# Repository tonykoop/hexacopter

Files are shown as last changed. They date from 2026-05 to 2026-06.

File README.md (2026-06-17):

# Hexacopter — Systems Integration for a Deliberately Grounded Aerial Platform

> *I was one of the first hobby DJI Phantom owners. I got beautiful aerial skyline photos — 10 of which were later juried into the permanent collection of the University of Minnesota Ambulatory Care Center through Art Force. I lost the Phantom to a fly-away during a demo at Bracketron. The community rebuilt me through a Kickstarter funded at 168% of goal by 94 backers. The replacement is a six-rotor DSLR-lift platform with a 3D-printed gimbal that I intentionally kept grounded until the flight-control stack could be validated. This repository is the engineering record of that build.*

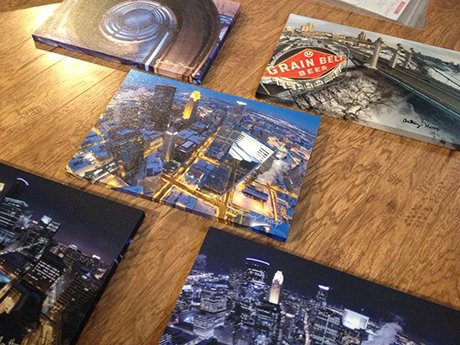
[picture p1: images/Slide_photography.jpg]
Phantom-era Minneapolis aerial skyline photographs printed as canvas wraps, laid out on a wood table


*Phantom-era Minneapolis aerials, printed as canvas wraps — the body of work the Kickstarter backers funded a more capable platform to extend.*

## What this is

Engineering documentation for a hexacopter aerial-photography platform that I designed, sourced, partially assembled, and then deliberately paused before flight testing. The next step was firmware-level speed-controller and flight-controller setup, and I was not willing to risk a multi-thousand-dollar crowdfunded airframe on a maiden flight that had not cleared a convincing validation path.

The build is currently at my parents' house, intact, ready to be picked up again. This repository captures the engineering work that *did* happen: the BOM, the design choices, the sketchbook entries, the engineering-notebook pages, the 3D-printed gimbal, the CAD, independent of the airframe ever flying.

## The story

### Phantom era — early adopter, beautiful aerials

I was one of the first hobby owners of the **DJI Phantom** when it launched in 2013. I got a string of beautiful aerial skyline photos that, for a brief moment before consumer drones became ubiquitous, felt like access to a perspective hardly anyone else had.

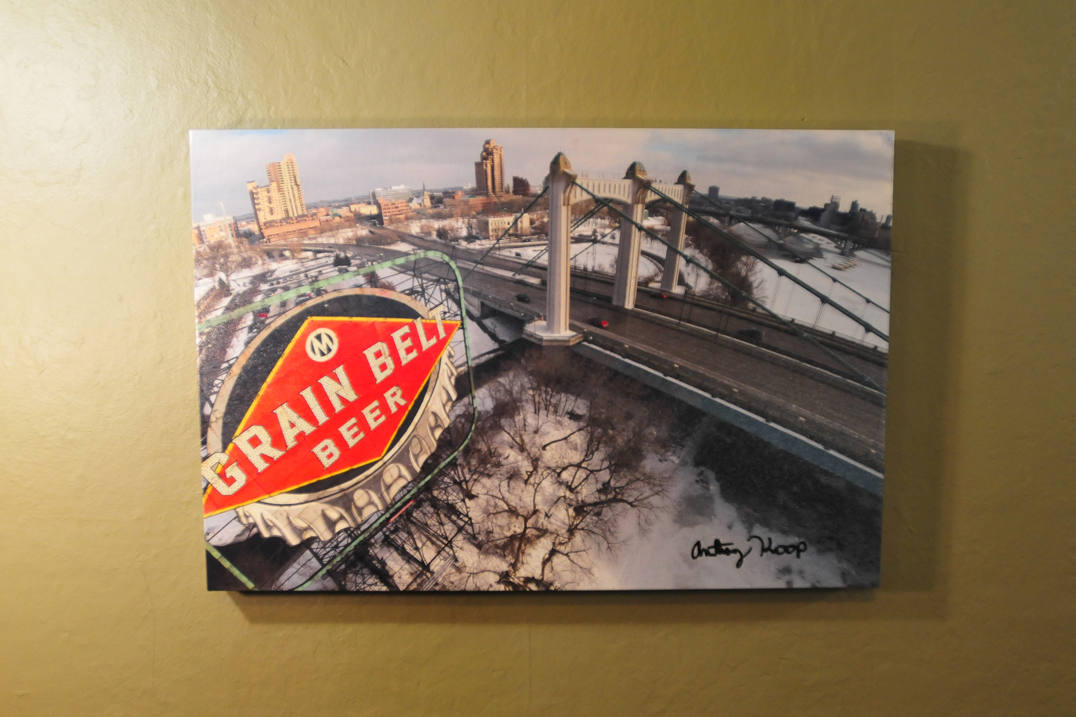
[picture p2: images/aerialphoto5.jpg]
Aerial photograph of the Grain Belt Beer sign and the Hennepin Avenue Bridge over the Mississippi River, printed as a signed canvas wrap


*A Phantom-era aerial — the Grain Belt Beer sign and the Hennepin Avenue Bridge over the Mississippi — printed as a signed canvas wrap.*

### Aerial work juried into a healthcare-facility installation

In September 2015, **Art Force** — the curatorial program that places original art into University of Minnesota healthcare facilities — juried **21 of my photographs into the permanent collection at the U of M Ambulatory Care Center**, including 10 aerial images. The selection was a paid licensing arrangement ($30 per use × 21 images), and the photographs have been printed and installed in the clinic since.

The aerial pieces in that collection are part of the same body of work the Kickstarter backers funded a more capable drone to extend.

### The fly-away

During a demonstration to coworkers at **Bracketron**, the Phantom executed a fly-away and was never seen again. Fly-aways were a known failure mode of early hobby drones; mine was almost certainly a compass-calibration or GPS-handoff event, but the diagnosis did not change the outcome. The drone and the GoPro mounted to it were gone. Coworkers, my brother, and I spent something like 20–30 collective hours ground-searching the area and never recovered it.

### Crowdfunded rebuild — the hexacopter

In March 2014 I launched a **Kickstarter** to crowdfund a more capable replacement aerial-photography platform. The campaign ran March 3 – April 1, 2014 and raised **$5,065 from 94 backers** — **168% of the $3,000 goal** — over 29 days. Backers were a mix of friends, coworkers, and strangers who had seen the Phantom-era aerial photos.

With the funds I:

- sourced a pre-built hexacopter frame kit specced for **DSLR camera lift capacity**
- selected and procured the electronics: flight controller, ESCs, motors, props, telemetry radio, FPV transmitter, receiver, and batteries
- designed and **3D-printed a custom gimbal** for the DSLR payload
- mechanically assembled the airframe, gimbal, and electronics
- wired the power distribution, signal lines, and telemetry

Four carbon-fiber motor arms with brushless motors and ESCs, laid out beside a digital caliper and steel rule

*Carbon-fiber motor arms with their brushless motors and ESCs, checked against a digital caliper and steel rule — component verification from the build.*

**Rewards delivered:** signed aerial prints (8″×10″, 11″×14″, 12″×18″), canvas wraps, and the bill-of-materials / build-log document.

**Reward still outstanding:** The top-tier backer reward — an aerial photo/video shoot within 250 miles of Minneapolis — was never delivered, because the platform never had its maiden flight. The build is paused, not closed.

### The decision to keep it grounded

The next step in 2014 was tuning: program the **speed controllers** (ESCs), configure the **flight controller** firmware, set up failsafes, and then fly increasingly careful test hops. I trusted the mechanical and electrical work. I did not yet trust the validation path strongly enough to put a crowdfunded aircraft in the air.

So I kept it grounded. The hexacopter went into storage at my parents' house and has been waiting since.

The engineering judgment I have made peace with is simple: **keeping it grounded was the right call at the time.** Hobby drone crashes from misconfigured firmware are common, and this build deserved a stronger validation chain than I had in hand. The good news is that the project is resumable rather than lost; the documentation ecosystem around platforms like ArduPilot, PX4, simulators, and safer bench-testing workflows is much better now than it was when I first built it.

## Why an unfinished build still belongs in the portfolio

The value here is not "I launched it." The value is in two things together:

**1. The documented systems work that did happen.**
- **Bill of materials** — a complete, sourced, costed component list for a DSLR-lifting hexacopter
- **Mechanical design** — frame selection, motor and prop choices, gimbal CAD, payload geometry
- **3D-printed gimbal** — early mechanism design work
- **Electronics architecture** — power distribution, ESC and flight-controller integration, telemetry radio, FPV link
- **Sketchbook and engineering-notebook entries** — design decisions and tradeoff thinking from the time, including first-principles geometric analysis of motor-to-prop clearance across quad/hex/octocopter configurations (June 2013)
- **Cross-domain integration** — mechanical, electrical, embedded firmware, data comms, and payload optics

**2. The decision to stop before flying.**
A maiden flight on an unvalidated stack carrying a crowdfunded airframe was a bad risk. The same judgment that says "do not fly this yet" is the judgment a UAV company wants in someone touching their hardware. Hobby drone crashes are common; this one didn't crash because I chose not to put it in the air.

A senior R&D engineer reading this should see: *here is someone who took on a multi-disciplinary integration project, carried the mechanical and electrical work to assembly, recognized when the validation gate for safe execution had not been met, and kept the platform grounded rather than bluffing past that limit.* That is the signal this repo is meant to carry.

## Engineering content (forthcoming)

Material exists in personal archives and at my parents' house; it will be added as recovered. README, license, and an initial set of photos are in; the engineering documents are being recovered from archives.

| Section | Status |
|---|---|
| Repo description, license | ✓ done |
| Story arc + framing | ✓ this README |
| Phantom-era aerial photos | ✓ done — hero + in-page aerial added |
| Selected Art Force / U of M Ambulatory Care Center pieces | forthcoming — selection of the 10 aerial images installed |
| Bill of materials | forthcoming — exists in engineering notebook |
| Mechanical design — frame + motor sizing | forthcoming |
| 3D-printed gimbal CAD + photos | forthcoming |
| Electronics architecture diagram | forthcoming |
| Sketchbook + engineering-notebook scans | forthcoming (parents' house archives) — June 2013 quad/hex/octocopter clearance derivations are top priority |
| Build photos | ✓ done — component-check photo added; more forthcoming |
| Firmware-tuning plan (for resumption) | forthcoming — ArduPilot / PX4 evaluation, bench-testing sequence, tethered-hover gate, maiden-flight gate |
| Outstanding-backer shoot list (private) | forthcoming — internal tracking, not for public posting |

## Cross-references

- **Art Force / U of M Ambulatory Care Center placement** — Aerial photographs selected for the permanent clinic installation are the body of work this hexacopter was built to extend. Documented in personal archives; selection licensed September 2015.
- **[wrfcoin](https://www.wrfcoin.com)** — a finished hexacopter would make an excellent **mobile sensor platform** for wrfcoin: the current sensor work is fixed-location ground-station based, but a UAV-mounted instrument package could capture vertical atmospheric profiles, micro-climate variation, and remote-area weather data the ground stations cannot reach.
- **General engineering portfolio** — this is the multi-disciplinary integration project in the personal-craft cluster, alongside [`woodworking`](https://github.com/tonykoop/woodworking) and [`chessboard-table`](https://github.com/tonykoop/chessboard-table). Where those repos document hand-craft, this one documents systems-engineering thinking applied to a hobby project.

## Repository structure

```text
hexacopter/
├── README.md                  ← you are here
├── LICENSE                    ← CC-BY 4.0
├── images/                    ← Phantom skyline photos, build photos, gimbal renders
└── (forthcoming)
    ├── art-force/             ← selection of the 10 aerial images installed at U of M
    ├── CAD/                   ← gimbal + payload-mount geometry
    ├── BOM/                   ← bill of materials, sourcing notes
    ├── electronics/           ← architecture diagram, ESC + FC documentation
    ├── notebook/              ← scanned sketchbook + engineering notebook entries
    └── firmware-plan/         ← tuning + maiden-flight plan (for resumption)
```

## License

Released under [CC-BY 4.0](LICENSE) — original written content, CAD, BOM, photographs, and engineering analysis in this repository are mine, free to reuse and adapt with credit. **Component selections and sourcing decisions documented here are personal-build choices for a hobby project; reproduce at your own risk.** The aerial photographs licensed to Art Force for the U of M Ambulatory Care Center installation are covered separately by that licensing arrangement and are not part of this CC-BY release.

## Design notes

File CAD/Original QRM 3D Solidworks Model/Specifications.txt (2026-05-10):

Dimensions*:		165 x 165 x 52 mm
Weight**:		200 gr
Battery:		2S 850mAh
Motor size:		18  x11 - 2000kv
Prop size:		5”
Control board size:	50 x 50 mm
Control board mounting:	4x M3 (44 x 44 mm)
Flyingtime:		+- 6min

* without propellers
** excluding battery

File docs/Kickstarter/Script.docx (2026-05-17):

OVERVIEW
1. Intro
2. Multirotor Frame

a. Tools needed to work with frames
b. Variety of frames
i. tri, quad, hex, octo,
ii. Y6, X8,
c. Common Dimensions
3. Flight Controller

a. Tools needed
b. What they do
c. common components & features to look for
d.

4. Transmitters

a. how they work with receivers
b. actual size image

5. Receivers
6. Camera

a. Commonly used for aerial photograpy
b. Interfaces with gimbal, telemetry
c. actual size image of gopro

7. Gimbal

a. What they do
b. How they work with receiver and flight controller

8. Motor

a. KV explanation
b. image of actual size motor
c.

9. ESC

10. Battery
11. Propellers
12. Other Accessories

RESEARCH

- DATABASE CREATION
- PART ELIMINATION/SELECTION
- PURCHASING

ASSEMBLY
1. Frame
2.
BATTERY CARE
FLIGHT CONTROLLER PROGRAMMING
TRANSMITTER PROGRAMMING
- RECEIVER BINDING

I have just concluded the data collection process (online shopping) for creating a Bill of Materials Database. It is the Excel spreadsheet named “BOM Database.xls”. I hope this document will be an invaluable tool for customizing your own build. I also just finished the first round of part elimination which I will explain below.

There are 8 main components to every basic DIY multirotor. They are highlighted in blue below. Those highlighted in yellow are the accessories for my customized build.

ITEM NO. | CATEGORY | COMPONENT | OPTIONS
1 | Hardware | Multirotor Frame | 21
2 | Electronics | Flight Contoller | 7
3 | Electronics | Transmitter | 13
4 | Electronics | Receiver | 8
5 | Accessories | Camera | 7
6 | Accessories | Gimbal | 7
7 | Electronics | Motor | 37
8 | Electronics | ESC | 23
9 | Electronics | Battery | 17
10 | Hardware | Propellers | 28
11 | Accessories | GPS Tracker | 1
| | # OF TOTAL POSSIBLE COMBINATIONS: | 303,447,292,512

Choose Specifications for your build:
When undertaking the task of building a multirotor, it’s important to first determine what you want to do with your multirotor. Applications and industries include but are not limited to aerial photography and videography, agricultural inspections, infra-red night vision, search and rescue, wildfire control, natural disaster surveillance, relief aid distribution, local package delivery, and real estate sales etc.

I have decided to build a hexacopter or octocopter capable of GPS stabilized flight, camera stabilization, first person view (FPV) transmission, and it must include a GPS tracker with an independent power source. This craft should have landing gear that easily allow for the addition of a camera gimbal. The central portion of the frame should be large enough to house the flight controller, GPS tracker, LED, batteries, and receiver.

Excel Spreadsheet: BOM Database
There are 13 tabs within the BOM Database. One tab each for the eleven components listed above, one called “BOM Summary” and another called “Scorecard”. If you have the document open within Excel, you’ll notice all the tabs near the bottom of the screen. Select the second tab labeled “1. Multirotor Frames”. There you’ll find 21 frame options with relevant data such as mass, price, distance between motor centers, and max prop size etc. The far right column in the table above indicates how many part options are available for that specific component. You are encouraged to add other parts from your own research to the database. This will help you find the best possible combination of parts. And there are literally billions of options. If one were to attempt a multirotor build by throwing a dart in the dark at each of the component lists, there would literally be 303 billion possible combinations. We’ll use some neat tricks in Excel to narrow down the number of possible options. Note: Please verify and double check that any data you use from the BOM Database is correct before purchasing and assembling your own multirotor.

What order to choose your components:
I suggest choosing your components in numerical order as shown in the table above. The first list of parts to narrow down are the multirotor frames followed by the flight controller, transmitter, and receiver. In this case, two accessories come next; the camera and the gimbal. I have put these before the motors, ESCs, and batteries because they contribute a significant amount of weight to the build. The final components to consider are any other accessories, in my case I’m adding an independent GPS tracker.

Round 1 of Elimination:
After having collected data on all the parts I’m considering for my build, I then begin to narrow down the options to those that suit my budget and needs. How you narrow down the parts for your build also depends on your budget and needs. During the first round of elimination on the frames I removed the most expensive frames and the smallest frames. This leaves me with 9 remaining frame options

1. Multirotor Frames

A similar process was conducted for the flight controllers, transmitters, receivers, cameras, gimbals, and motors. Two of the seven flight controllers were removed due to budget constraints. Choosing a transmitter to fly the craft was easy because I already own one. The receiver was also easy to choose because I plan to use the receiver recommended for my transmitter. I already own the camera I plan to use and all gimbals incompatible with my GoPro camera have been removed from consideration. This first round of elimination reduced the number of possible combinations by 99.98%. But remember 303 billion is a huge number, we still have 49.3 million possible combinations. Hopefully the second round of elimination will significantly reduce this number again, especially considering we haven’t eliminated any ESCs, batteries, or propellers yet.

BOM Summary – Sub Table 3

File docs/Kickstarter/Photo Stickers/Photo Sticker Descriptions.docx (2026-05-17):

Option 1 - Done

Ramp Sprial #1

This photo was taken with a GoPro Hero 3+ Black Edition camera on a DJI Phantom Quadcopter flown by Tony Koop on January 17th, 2014 at 6:17pm. The objective of this flight was to capture the Minneapolis skyline. While returning for landing, I noticed the unusual perspective of this parking ramp and knew I had to shoot it. This was shot during the same flight as Downtown Minneapolis #2.

Option 2 - Done

Grain Belt Beer

This photo was taken with a GoPro Hero 3+ Black Edition camera on a DJI Phantom Quadcopter flown by Tony Koop on January 11th, 2014 at 2:11pm. This sign was originally erected in 1941 for $5000. The circumscribed letter M is a tribute to the brewery’s former name, Minneapolis Brewing Company. Grain Belt is now owned by August Schell Brewing Company which purchased the rights in 2002.

Option 3 - Done

Downtown Minneapolis #1

This photo was taken with a GoPro Hero 3+ Black Edition camera on a DJI Phantom Quadcopter flown by Tony Koop on January 11th, 2014 at 7:24pm. My initial objective for this flight was to photograph the Orpheum Theatre. It turned into my first attempt at photographing the Minneapolis skyline when I couldn’t quite get the perspective I wanted of the Orpheum.

Option 4

Minneapolis from Loring Park

This photo was taken with a GoPro Hero 3+ Black Edition camera on a DJI Phantom Quadcopter flown by Tony Koop on January 11th, 2014 at 2:41pm.

Option 5

Downtown Saint Paul

This photo was taken with a GoPro Hero 3+ Black Edition camera on a DJI Phantom Quadcopter flown by Tony Koop on January 18th, 2014 at 4:08pm.

Option 6 – Done

Downtown Minneapolis #2

This photo was taken with a GoPro Hero 3+ Black Edition camera on a DJI Phantom Quadcopter flown by Tony Koop on January 17th, 2014 at 6:14pm. It was the night before the Metrodome fell to make way for the new stadium. Damn it was cold. The atmosphere was crystal clear and frigid at 6°F as shown on the TCF Tower just to the right of the Foshay. Three minutes later I shot Ramp Spiral #1.

Option 7

Downtown Minneapolis #3

This photo was taken with a GoPro Hero 3+ Black Edition camera on a DJI Phantom Quadcopter flown by Tony Koop on January 18th, 2014 at 5:29pm.

Option 8

Target HQ

This photo was taken with a GoPro Hero 3+ Black Edition camera on a DJI Phantom Quadcopter flown by Tony Koop on January 29th, 2014 at 6:05pm. The display at the top of this building was upgraded from 3M light pipes to LEDs in 2011, just ten years after the building properly known as Target Plaza South was completed.

Option 9 - Done

Loring Park

This photo was taken with a GoPro Hero 3+ Black Edition camera on a DJI Phantom Quadcopter flown by Tony Koop on January 11th, 2014 at 2:46pm. If you look closely - which I’m sure you will – you might notice some interesting footprint patterns in the snow. Now known as Loring Park and Loring Lake, this park that butts up next to downtown was originally named Central Park and Johnson Lake.

Option 10

Ramp Spiral #2

This photo was taken with a GoPro Hero 3+ Black Edition camera on a DJI Phantom Quadcopter flown by Tony Koop on January 18th, 2014 at 4:14pm. Having been inspired by the first ramp I shot in Minnepolis, I attempted to shoot this ramp at the Science Museum of Minnesota in downtown Saint Paul.

Option 11 - Done

The Secret Option

This photo was taken with a GoPro Hero 3+ Black Edition camera on a DJI Phantom Quadcopter flown by Tony Koop on January 29th, 2014 at 5:39pm. This is a one of a kind. No other Kickstarter backers received this photo. The Basilica of Saint Mary was established by Pope Pius XI and was the first basilica in the US.

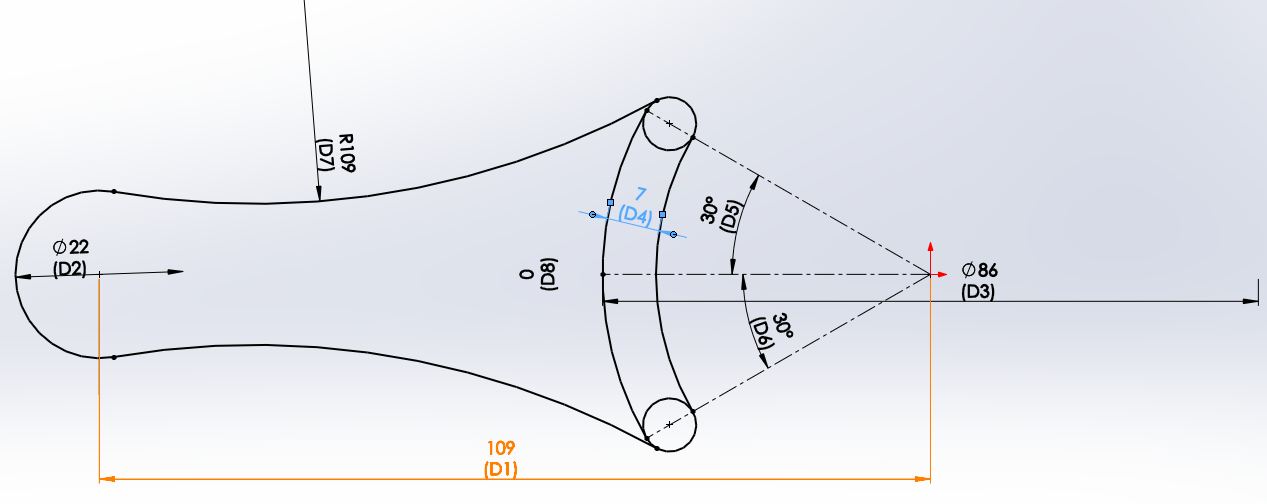
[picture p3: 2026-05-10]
CAD/Quadcopter/Bottom Arm Design Table Parameters.JPG

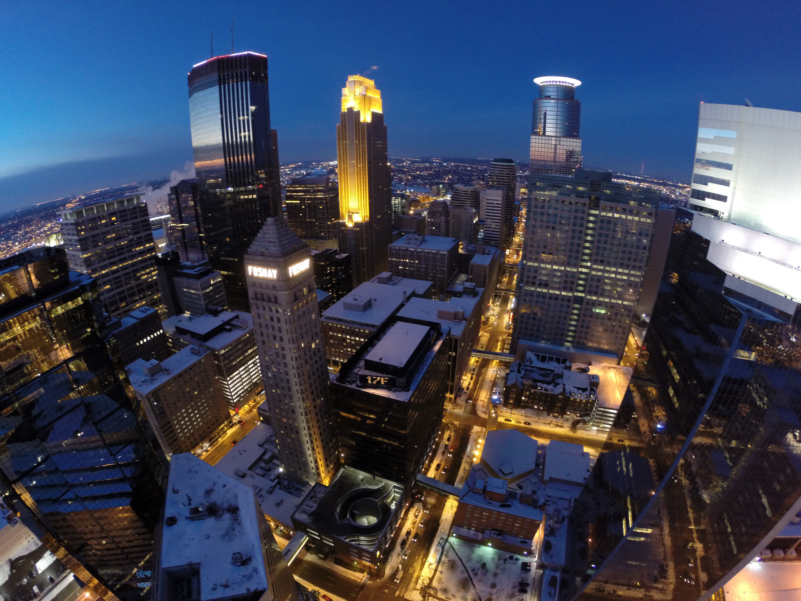
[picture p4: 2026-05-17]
docs/Kickstarter/WHCC/B Side/G0052918.JPG

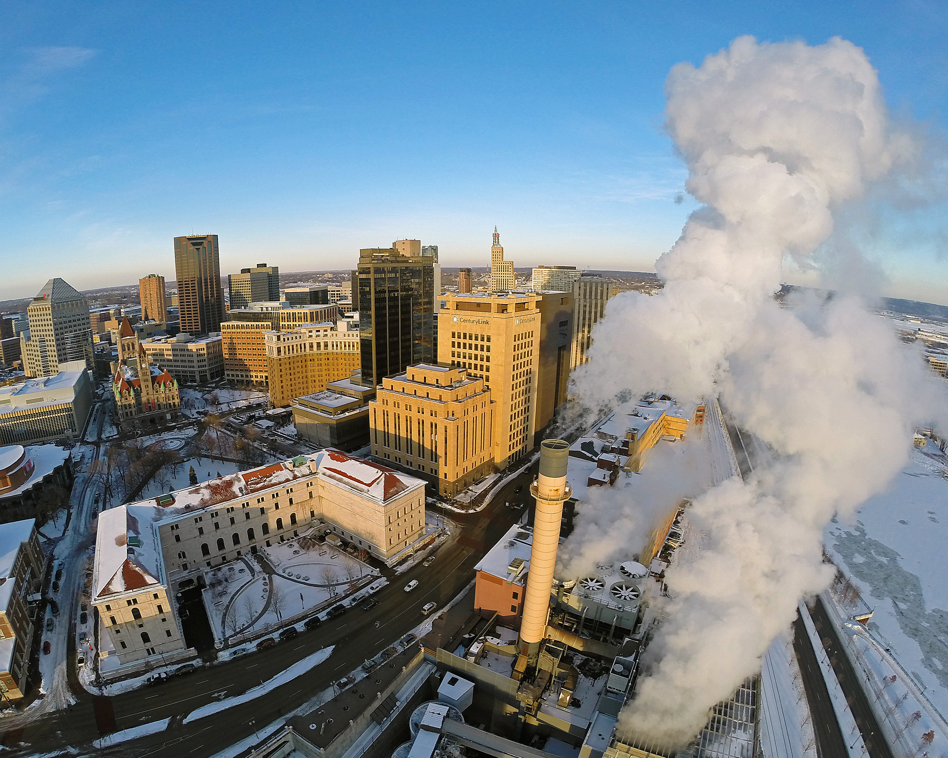
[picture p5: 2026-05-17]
docs/Kickstarter/Replacement photos/G0032023e810.jpg

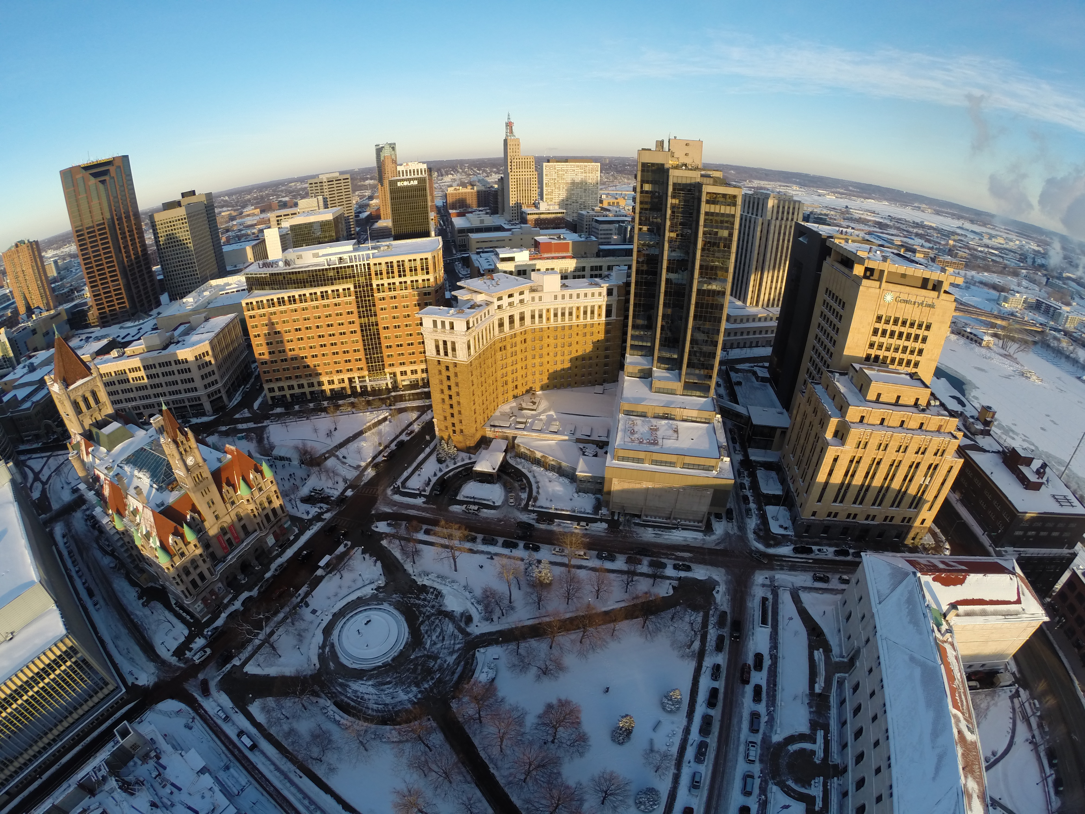
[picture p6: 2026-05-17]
docs/Kickstarter/WHCC/B Side/G0032110.JPG

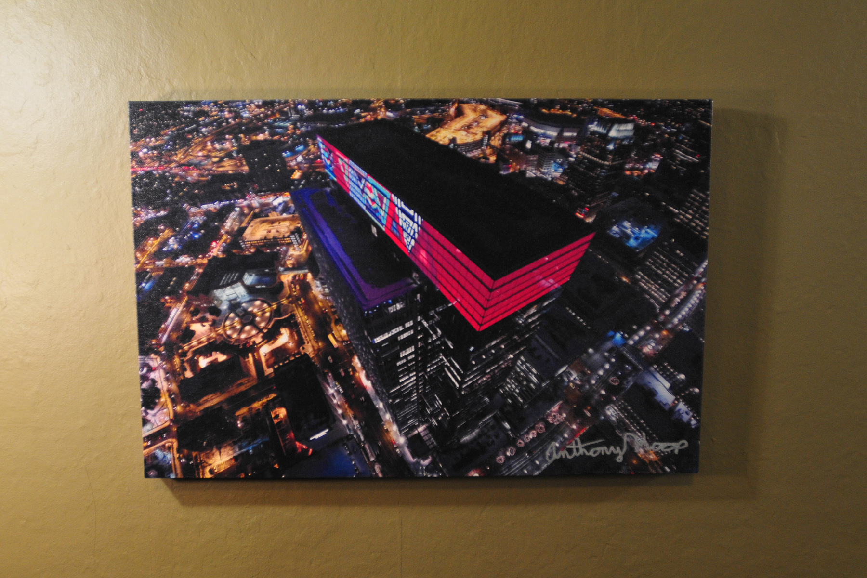
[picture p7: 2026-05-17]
images/aerialphoto6.jpg

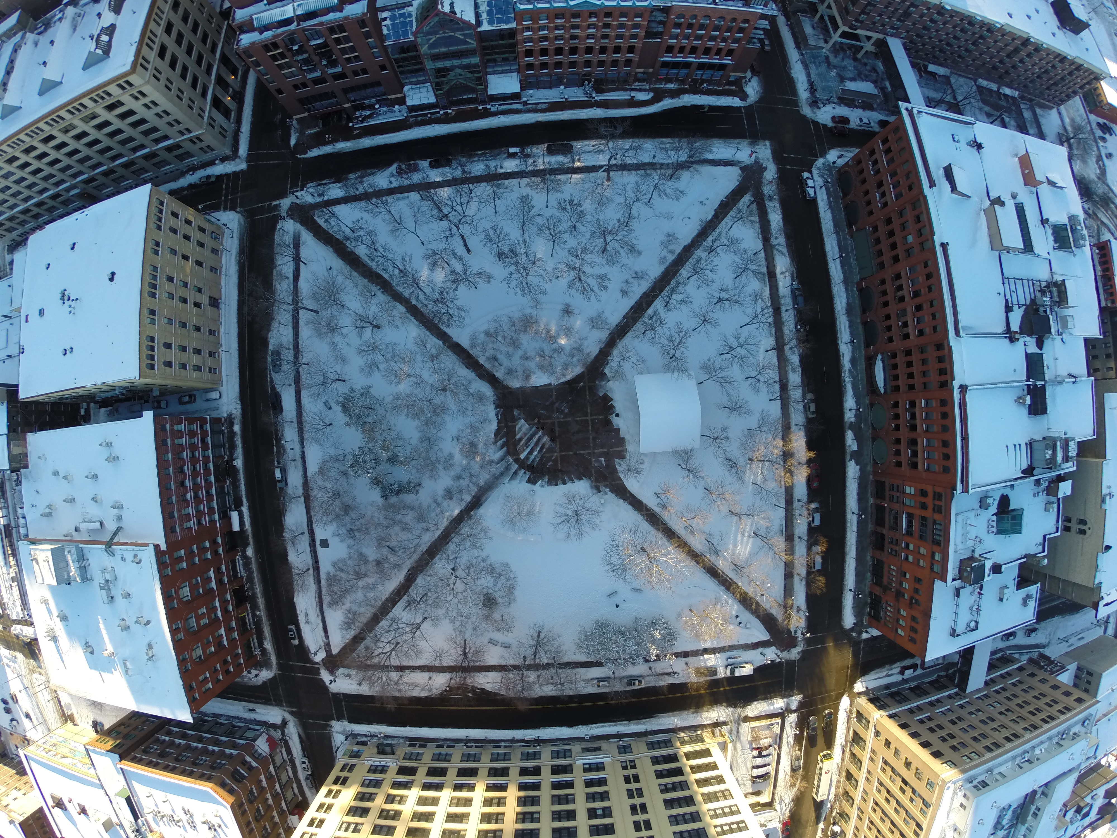
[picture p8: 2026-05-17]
docs/Kickstarter/WHCC/B Side/G0021763.JPG

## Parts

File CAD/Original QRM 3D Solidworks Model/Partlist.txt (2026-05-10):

Motor: 		18-11 2000kv Micro Brushless Outrunner (10g)
ESC: 		H-KING 10A Fixed Wing Brushless Speed Controller
Props: 		5x3 Propellers (Standard and Counter Rotating) (6pc)
Prop adaptors: 	Prop adapter w/ Alu Cone M5x2mm shaft (Grub Screw Type)
Battery: 	Turnigy nano-tech 850mah 2S 25~40C Lipo Pack
Control board: 	HobbyKing Quadcopter Control Board V2.1 (Atmega168PA)

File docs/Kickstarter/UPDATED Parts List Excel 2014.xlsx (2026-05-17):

Parts List
ITEM | PART DESCRIPITION | REF. DES. | PART NUMBER | QUANTITY | UNIT COST | EXTENDED COST | WEB ADDRESS
1 | HK Pilot Mega V2.5 | APM 2.5 | 9387000016 | 1 | 75.79 | 75.79 | http://hobbyking.com/hobbyking/store/__37328__HKPilot_Mega_V2_5_Flight_Controller_USB_GYRO_ACC_MAG_BARO.html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
2 | NEO-6M GPS Module | GPS | 387000004 | 1 | 22.49 | 22.49 | http://hobbyking.com/hobbyking/store/__54795__NEO_6M_GPS_Module_US_Warehouse_.html?strSearch=neo%206m
3 | NTM Prop Drive 28-36 1000kV Brushless Motors | MOTOR | 281052552799 | 8 | 16.12 | 128.96 | http://hobbyking.com/hobbyking/store/__42709__NTM_Prop_Drive_28_36_1000KV_400W_Brushless_Motor_US_Warehouse_.html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
4 | NTM Prop Drive 28 Brushless Motor Adapter | ADAPTER | NTM28-ACC | 8 | 1.89 | 15.12 | http://hobbyking.com/hobbyking/store/__16719__NTM_Prop_Drive_28_Series_Accessory_Pack.html
5 | AFRO 30A Speed Control | ESC | 9192000124-0 | 8 | 13.97 | 111.76 | http://hobbyking.com/hobbyking/store/__52338__Afro_ESC_30Amp_Multi_rotor_Motor_Speed_Controller_SimonK_Firmware_US_Warehouse_.html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
6 | AFRO ESC Programmer | ESC PROG. | 9171000243 | 1 | 7.35 | 7.35 | http://hobbyking.com/hobbyking/store/__48057__Afro_ESC_USB_Programming_Tool_USA_Warehouse_.html
7 | Turnigy 4s 5000mAh LiPo battery | BATTERY | T50004S-20HC | 4 | 25.47 | 101.88 | http://hobbyking.com/hobbyking/store/__18631__Turnigy_5000mAh_4S1P_14_8v_20C_hardcase_pack_USA_Warehouse_.html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
8 | 11x4.7 Carbon Fiber Propeller | PROP | 445000049-0 | 6 | 8.19 | 49.14 | http://hobbyking.com/hobbyking/store/__25689__Carbon_Fiber_Propellers_11X4_7_LH_and_RH_Rotation_Pair.html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
9 | Boscam 2000mW 5.8 GHz Video Transmitter | VID. TX | 263000022-0 | 1 | 123.48 | 123.48 | http://hobbyking.com/hobbyking/store/__46362__Boscam_Thunderbolt_2000mW_5_8GHz_FPV_Transmitter.html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
10 | Boscam 5.8GHz receiver | VID. RX | RC305Receiver | 1 | 24.99 | 24.99 | http://hobbyking.com/hobbyking/store/__15415__Boscam_RC305_5_8Ghz_8_Channel_AV_Receiver.html?strSearch=rc305
11 | 7in TFT Analog Screen | SCREEN | BW7MY | 1 | 31.28 | 31.28 | http://www.amazon.com/gp/product/B007SLDF7O/ref=oh_details_o06_s00_i00?ie=UTF8&psc=1
12 | 433 MHz Telemetry Combo | TELEMETRY | 9387000030-0 | 1 | 32.04 | 32.04 | http://hobbyking.com/hobbyking/store/__42847__FPV_433Mhz_Radio_Telemetry_Kit_100mW_V1_1.html
13 | Turnigy 9X 2.4GHz Transmitter & Receiver | TRANSMITTER | TX-9X-M2 | 1 |  | 69.97 | http://hobbyking.com/hobbyking/store/__19673__Turnigy_9X_9Ch_Transmitter_w_Module_8ch_Receiver_Mode_2_v2_Firmware_USA_Warehouse_.html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
14 | Sony CCD 700TVL Camera | CAM | 350000001 | 1 |  | 34.74 | http://hobbyking.com/hobbyking/store/__13197__1_3_inch_Sony_CCD_Video_Camera_700TV_Lines_F1_2_PAL_.html
15 | 2.8mm FPV Wide Angle Lens | N/A | FPV_CCDN | 1 | 16.99 | 16.99 | http://hobbyking.com/hobbyking/store/__13434__1_3_inch_SONY_CCD_Video_Camera_NTSC_.html
16 | MinimOSD | OSD | 387000015 | 1 | 19.9 | 19.9 | http://hobbyking.com/hobbyking/store/__54797__Minim_OSD_v1_1_US_Warehouse_.html
17 | FTDI Breakout Board | FTDI | 9716 | 1 | 14.95 | 14.95 | https://www.sparkfun.com/products/9716
18 | Circular Polarized 5.8 GHz antenna set SHORT | ANT. | 435000044-0 | 1 | 11.34 | 11.34 | http://hobbyking.com/hobbyking/store/__43703__5_8GHz_Circular_Polarized_Antenna_RP_SMA_Set_Short_.html
19 | Turnigy 3s 2200 Transmitter Pack | TRANS BATT. | 9171000183 | 1 | 13.17 | 13.17 | http://hobbyking.com/hobbyking/store/__45020__Turnigy_9XR_Safety_Protected_11_1v_3s_2200mAh_1_5C_Transmitter_Pack_USA_warehouse_.html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
20 | .75in Aluminum Square Tubing 6ft | LANDING | 215691 | 1 | 22.88 | 22.88 | http://www.lowes.com/pd_215691-37672-11388_0__?productId=3053575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
21 | .5in Aluminum Square Tubing 4ft | ARMS | T312063 | 1 | 4.98 | 4.98 | https://www.metalsdepot.com/products/alum2.phtml?page=tube&LimAcc=%20&aident=
22 | McMasterCarr Bolts | N/A | N/A | 1 | 20 | 20 | http://www.mcmaster.com/
23 | McMasterCarr Rubber | N/A | 8981K14 (http://www.mcmaster.com/OrdHist/OrdHist.aspx?dtrngpref=ONE_YR) | 1 | 7.83 | 7.83 | http://www.mcmaster.com/#catalog/120/3546/=rrqa0g
24 | Zip Ties | N/A | N/A | 3 | 5 | 15 | Walmart.com
25 | Low Voltage Alarm | ALARM | Voltage-Alarm | 2 | 3.92 | 7.84 | https://www.hobbyking.com/hobbyking/store/__34120__Hobbyking_2_8S_Cell_Checker_with_Low_Voltage_Alarm_US_Warehouse_.html
26 | XT60 Battery Connector | N/A | 015000103-0 | 2 | 4.69 | 9.38 | https://www.hobbyking.com/hobbyking/store/__52412__Black_XT60_Male_and_Female_5_Pairs_Bag_US_Warehouse_.html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
27 | 12 Gauge Wire 6ft. | N/A | R12A1062-06 and B12A1062-06 | 2 | 2.38 | 9.52 | https://www.hobbyking.com/hobbyking/store/__42750__Turnigy_Pure_Silicone_Wire_12AWG_1mtr_RED_USA_warehouse_.html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 | https://www.hobbyking.com/hobbyking/store/__41169__Turnigy_Pure_Silicone_Wire_12AWG_1mtr_BLACK_USA_warehouse_.html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
28 | Various Wire Shielding | N/A | ES-02-6mm | 6 | 0.49 | 2.94 | https://www.hobbyking.com/hobbyking/store/__9552__Wire_Mesh_Guard_Black_6mm_1mtr_.html
29 | HXT 4.0 | N/A | AM1009x10 | 2 | 4.46 | 8.92 | https://www.hobbyking.com/hobbyking/store/__30921__HXT_4mm_Gold_Connector_w_Protector_10pcs_set_US_Warehouse_.html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
30 | HD DVR | DVR | 428000001 | 1 | 52.22 | 52.22 | https://www.hobbyking.com/hobbyking/store/__25321__SD_DVR_High_Resolution_Digital_Video_Recorder_for_FPV.html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
TOTAL: |  |  |  |  |  | 1066.85
OPTIONAL, BUT RECOMMENDED:
1 | HK Pilot Mega Bundle |  | 387000043-0 | 1 | 169.99 | 169.99 | http://hobbyking.com/hobbyking/store/__52391__HKPilot_Mega_2_5_2_Master_Set_With_OSD_LEA_6H_GPS_Power_module_Telemetry_Radio_915Mhz_XT_60_.html
2

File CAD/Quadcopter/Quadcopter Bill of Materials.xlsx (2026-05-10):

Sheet: Scorecard
Elective BOM Option | Motor Model | Hover Flight Time (minutes) | Hover Score | Weight (grams) | Weight Score | Additional Payload (grams) | Additional Payload Score | Throttle at Hover (%) | Throttle At Hover Score | Total Price($US) | Price | Total Score (higher is better) | Weighted Total Score Option 1 | Weighted Total Score Option 2 | ecalc Link
7 | 4822-490 | 14.8 | 7 | 2011 | 3 | 454 | 1 | 65.00 | 1.00 | $441.21 | 3 | 15 | 25 | 34.25 | Link (http://www.ecalc.ch/xcoptercalc.htm?ecalc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)
6 | 4822-390 | 19.2 | 10 | 2239 | 1 | 1191 | 5 | 50.00 | 4.00 | $472.83 | 1 | 21 | 35.5 | 46.25 | Link (http://www.ecalc.ch/xcoptercalc.htm?ecalc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)
10 | 4225-390 | 19.9 | 11 | 2191 | 2 | 1106 | 3 | 51.00 | 3.00 | $460.83 | 2 | 21 | 35.75 | 48.25 | Link (http://www.ecalc.ch/xcoptercalc.htm?ecalc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)
8 | 4822-570 | 14.4 | 6 | 1958 | 4 | 1117 | 4 | 50.00 | 5.00 | $416.37 | 4 | 23 | 35 | 44 | Link (http://www.ecalc.ch/xcoptercalc.htm?ecalc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)
3 | 2216-800 | 13.1 | 3 | 1716 | 10 | 764 | 2 | 53.00 | 2.00 | $321.43 | 11 | 28 | 40.25 | 51 | Link (http://www.ecalc.ch/xcoptercalc.htm?ecalc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)
9 | 4822-690 | 14 | 5 | 1946 | 5 | 2094 | 9 | 36.00 | 9.00 | $416.37 | 4 | 32 | 47.25 | 55.75 | Link (http://www.ecalc.ch/xcoptercalc.htm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)
2 | 3536-1050 | 11.3 | 1 | 1936 | 6 | 2706 | 11 | 28.00 | 10.00 | $405.99 | 6 | 34 | 47.75 | 53.25 | Link (http://www.ecalc.ch/xcoptercalc.htm?ecalc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)
4 | 3525-650 | 16 | 8 | 1798 | 8 | 1396 | 6 | 42.00 | 6.00 | $392.85 | 8 | 36 | 54.5 | 68.5 | Link (http://www.ecalc.ch/xcoptercalc.htm?ecalc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)
11 | 4225-610 | 16.2 | 9 | 1910 | 7 | 1586 | 8 | 40.00 | 7.00 | $404.37 | 7 | 38 | 58.25 | 72.5 | Link (http://www.ecalc.ch/xcoptercalc.htm?ecalc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)
5 | 3525-850 | 13.8 | 4 | 1664 | 11 | 1418 | 7 | 39.00 | 8.00 | $383.66 | 9 | 39 | 56 | 67.75 | Link (http://www.ecalc.ch/xcoptercalc.htm?ecalc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)
1 | 3530-1150 | 12.7 | 2 | 1756 | 9 | 2455 | 10 | 28.00 | 11.00 | $354.67 | 10 | 42 | 58.5 | 67.5 | Link (http://www.ecalc.ch/xcoptercalc.htm?ecalc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)

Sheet: Summary of Scores
Rank Worst to Best | No Weight | Weight Option 1 | Weight Option 2
11 | 4822-490 | 4822-490 | 4822-490
10 | 4822-390 | 4822-570 | 4822-570
9 | 4225-390 | 4822-390 | 4822-390
8 | 4822-570 | 4225-390 | 4225-390
7 | 2216-800 | 2216-800 | 2216-800
6 | 4822-690 | 4822-690 | 3536-1050
5 | 3536-1050 | 3536-1050 | 4822-690
4 | 3525-650 | 3525-650 | 3530-1150
3 | 4225-610 | 3525-850 | 3525-850
2 | 3525-850 | 4225-610 | 3525-650
1 | 3530-1150 | 3530-1150 | 4225-610

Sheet: Motors
Option | Brand | Line | Model | Lipo Cells | KV (rpm/v) | No Load Current (Amps) | Max Watts | Operating Current (Amps) | Max Current (Amps) | Internal Resistance (ohm) | Number of Poles | Shaft Size (mm) | Diameter (mm) | Case Length (mm) | Mass (grams) | Recommended ESC (Amp Rating) | Price (US$) | Link
1 | Turnigy | Aerodrive SK3 | 3530-1150 | 3-4 | 1150 |  | 330 | ? | 24 | 0.069 | 28 | 4 | 37 | 31 | 76 | 30 | $25.01 | Link (http://www.hobbyking.com/hobbyking/store/__18160__Turnigy_Aerodrive_SK3_3530_1150kv_Brushless_Outrunner_Motor.html)
2 | Turnigy | Aerodrive SK3 | 3536-1050 | 3-4 | 1050 |  | 505 | ? | 34 | 0.039 | 16 | 5 | 37 | 37 | 110 | 40 | $28.28 | Link (http://www.hobbyking.com/hobbyking/store/__18162__Turnigy_Aerodrive_SK3_3536_1050kv_Brushless_Outrunner_Motor.html)
3 | Turnigy | Multistar | 2216-800 | 2-3 | 800 | 0.50 | 222 | ? | 20 | 0.169 | 12? | 5 | 28 | 32.0 | 66 | 25 | $16.70 | Link (http://www.hobbyking.com/hobbyking/store/__39037__Turnigy_Multistar_2216_800Kv_Multi_Rotor_Outrunner.html)
4 | Turnigy | Multistar | 3525-650 | 4 | 650 | 0.50 | 250 | 14 | 17 | 0.178 | 14 | 4 | 35 | 25.0 | 58 | 25 | $25.11 | Link (http://www.hobbyking.com/hobbyking/store/__36765__Turnigy_Multistar_3525_650Kv_14Pole_Multi_Rotor_Outrunner.html)
5 | Turnigy | Multistar | 3525-850 | 3 | 850 | 0.60 | 250 | 19 | 23 | 0.101 | 14 | 4 | 35 | 25.0 | 58 | 25 | $27.60 | Link (http://www.hobbyking.com/hobbyking/store/__36767__Turnigy_Multistar_3525_850Kv_14Pole_Multi_Rotor_Outrunner.html)
6 | Turnigy | Multistar | 4822-390 | 6 | 390 | 0.25 | 300 | 11 | 15 | 0.170 | 22 | 6 | 47.5 | 25.0 | 98 | 40 | $30.99 | Link (http://www.hobbyking.com/hobbyking/store/__26957__Turnigy_Multistar_4822_390Kv_22Pole_Multi_Rotor_Outrunner.html)
7 | Turnigy | Multistar | 4822-490 | 4-6 | 490 | 0.45 | 300 | 12 | 17 | 0.104 | 22 | 6 | 47.5 | 25.0 | 98 | 20-45 | $30.99 | Link (http://www.hobbyking.com/hobbyking/store/__26958__Turnigy_Multistar_4822_490Kv_22Pole_Multi_Rotor_Outrunner.html)
8 | Turnigy | Multistar | 4822-570 | 4 | 570 | 0.65 | 310 | 15 | 21 | 0.092 | 22 | 6 | 47.5 | 25.0 | 98 | 25 | $30.99 | Link (http://www.hobbyking.com/hobbyking/store/__26959__Turnigy_Multistar_4822_570Kv_22Pole_Multi_Rotor_Outrunner.html)
9 | Turnigy | Multistar | 4822-690 | 4 | 690 | 0.85 | 320 | 16 | 22 | 0.052 | 22 | 6 | 47.5 | 25.0 | 95 | 25 | $30.99 | Link (http://www.hobbyking.com/hobbyking/store/__26960__Turnigy_Multistar_4822_690Kv_22Pole_Multi_Rotor_Outrunner.html)
10 | Turnigy | Multistar | 4225-390 | 6 | 390 | 0.20 | 330 | 11 | 15 | 0.240 | 16 | 6 | 42 | 24.5 | 86 | 40 | $27.99 | Link (http://www.hobbyking.com/hobbyking/store/__26963__Turnigy_Multistar_4225_390Kv_16Pole_Multi_Rotor_Outrunner.html)
11 | Turnigy | Multistar | 4225-610 | 4 | 610 | 0.30 | 330 | 16 | 22 | 0.091 | 16 | 6 | 42 | 24.5 | 86 | 25 | $27.99 | Link (http://www.hobbyking.com/hobbyking/store/__26964__Turnigy_Multistar_4225_610Kv_16Pole_Multi_Rotor_Outrunner.html)
 |  |  |  |  |  |  |  |  |  |  |  |  |  |  | 2014-03-30 22:00

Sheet: ESC
BRAND | MODEL | Continuous Current (A) | Burst Current (A) | Lipo Cells | MASS (g) | PRICE
Turnigy | Plush 18 Amp ESC | 18 | 22 | 2-4 | 19 | $12.15
HURC | 18 Amp Brushless Motor ESC | 18 | ? | 2-4 | 25 | $13.95
HURC | 22 Amp Brushless Motor ESC | 22 | 25 | 2-4 | 28 | $14.95
Turnigy | Plush 25 Amp ESC | 25 | 35 | 2-4 | 22 | $12.61
Turnigy | Basic 25 Amp v3.1 ESC | 25 | 28 | 2-4 | 22 | $16.04 | http://www.hobbyking.com/hobbyking/store/__33296__TURNIGY_Basic_25A_v3_1_Speed_Controller_USA_Warehouse_.html
Turnigy | AE-25A ESC | 25 | 35 | 2-4 | 25 | $10.71 | http://www.hobbyking.com/hobbyking/store/__31996__Turnigy_AE_25A_Brushless_ESC_USA_Warehouse_.html
Turnigy | Plush 30 Amp ESC | 30 | 40 | 2-4 | 25 | $12.19
HURC | 30 Amp Brushless Motor ESC | 30 | 35 | 2-4 | 30 | $16.95
Turnigy | dlux 30Amp SBEC | 30 | 40 | 2-4 | 23 | $17.65 | http://www.hobbyking.com/hobbyking/store/__26499__Turnigy_dlux_30A_SBEC_Brushless_Speed_Controller_w_Data_Logging_2s_4s_USA_Warehouse_.html
Turnigy | Plush 40 Amp ESC | 40 | 55 | 2-6 | 33 | $22.17
HURC | 40 Amp Brushless Motor ESC | 40 | 45 | 2-4 | 38 | $19.95
 | LINK
 | http://www.hobbyking.com/hobbyking/store/__30683__TURNIGY_Plush_18amp_Speed_Controller_US_Warehouse_.html
 | http://www.hobbyking.com/hobbyking/store/__36903__TURNIGY_Plush_25amp_Speed_Controller_USA_Warehouse_.html
 | http://www.hobbyking.com/hobbyking/store/__2164__TURNIGY_Plush_30amp_Speed_Controller.html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
 | http://www.hobbyking.com/hobbyking/store/__41152__TURNIGY_Plush_40amp_Speed_Controller_USA_warehouse_.html

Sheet: BOM Calculator
DETERMINED PARTS |  |  |  |  |  |  | 2014-03-30 22:00
ITEM NO. | CATEGORY | PART NAME | PART SPECS | QTY. | MASS EACH (g) | TOTAL MASS (g) | PRICE EACH | TOTAL PRICE
1 | Frame | Quadcopter | Turnigy Talon Quadcopter V2.0 (without landing feet) | 1 | 242 | 242 | $56.39 | $56.39
2 | Electronics | Control Board | KK2.0 Multi-rotor LCD Flight Controller | 1 | 18 | 18 | $29.99 | $29.99
3 | Electronics | Receiver | Turnigy 9X 2.4GHz 8Ch Receiver (V2) | 1 | 18 | 18 | $9.11 | $9.11
4 | Hardware | Miscellaneous | Electrical Tape, Solder, Cable Ties, Etc. | 1 | 10 | 10 | $0.00 | $0.00
5 | Accessories | Gimbal | Arris CM2000 | 1 | 195 | 195 | $0.00 | $0.00
6 | Accessories | Camera | Gopro Hero 3 - Black Edition | 1 | 75 | 75 | $0.00 | $0.00
7 | Frame | Landing Gear | ATG Carbon Fiber Landing Skid Kit | 1 | 284 | 284 | $45.89 | $45.89
8 | Hardware | Propellers | 12x6 Carbon Fiber Propellers | 4 | 15 | 60 | $6.00 | $24.00
TOTALS |  |  | Determined Parts: | 11 | Determined Mass: | 902 | Determined Price: | $165.38
ELECTIVE PARTS
1 | Aerodrive SK3-3530-1150
ITEM NO. | CATEGORY | PART NAME | PRODUCT NAME | QTY. | MASS EACH (g) | TOTAL MASS (g) | PRICE EACH | TOTAL PRICE
9 | Electronics | Motor | Aerodrive SK3-3530-1150 | 4 | 76 | 304 | $25.01 | $100.04
10 | Electronics | ESC | Tunigy Plush 25A Speed Controller (35A Burst) | 4 | 22 | 88 | $12.61 | $50.44
11 | Electronics | Battery | Turnigy nano-tech 5000mah 3S1P 45C | 1 | 462 | 462 | $38.81 | $38.81
TOTALS |  |  |  |  | Elective Mass: | 854 | Elective Price: | $189.29
 |  |  |  |  | Total Mass: | 1756 | Total Price: | $354.67
 |  |  |  |  | Total Pounds: | 3.87
2 | Aerodrive SK3-3536-1050
ITEM NO. | CATEGORY | PART NAME | PRODUCT NAME | QTY. | MASS EACH (g) | TOTAL MASS (g) | PRICE EACH | TOTAL PRICE
9 | Electronics | Motor | Aerodrive SK3-3536-1050 | 4 | 110 | 440 | $28.28 | $113.12
10 | Electronics | ESC | Tunigy Plush 40A Speed Controller (55A Burst) | 4 | 33 | 132 | $22.17 | $88.68
11 | Electronics | Battery | Turnigy nano-tech 5000mah 3S1P 45C | 1 | 462 | 462 | $38.81 | $38.81
TOTALS |  |  |  |  | Elective Mass: | 1034 | Elective Price: | $240.61
 |  |  |  |  | Total Mass: | 1936 | Total Price: | $405.99
 |  |  |  |  | Total Pounds: | 4.27
3 | Multistar 2216-800
ITEM NO. | CATEGORY | PART NAME | PRODUCT NAME | QTY. | MASS EACH (g) | TOTAL MASS (g) | PRICE EACH | TOTAL PRICE
9 | Electronics | Motor | Multistar 2216-800 (2-3 cell) | 4 | 66 | 264 | $16.70 | $66.80
10 | Electronics | ESC | Tunigy Plush 25A Speed Controller (35A Burst) | 4 | 22 | 88 | $12.61 | $50.44
11 | Electronics | Battery | Turnigy nano-tech 5000mah 3S1P 45C | 1 | 462 | 462 | $38.81 | $38.81
TOTALS |  |  |  |  | Elective Mass: | 814 | Elective Price: | $156.05
 |  |  |  |  | Total Mass: | 1716 | Total Price: | $321.43
 |  |  |  |  | Total Pounds: | 3.78
4 | Multistar 3525-650
ITEM NO. | CATEGORY | PART NAME | PRODUCT NAME | QTY. | MASS EACH (g) | TOTAL MASS (g) | PRICE EACH | TOTAL PRICE
9 | Electronics | Motor | Multistar 3525-650 (4 cells) | 4 | 58 | 232 | $25.11 | $100.44
10 | Electronics | ESC | Tunigy Plush 25A Speed Controller (35A Burst) | 4 | 22 | 88 | $12.61 | $50.44
11 | Electronics | Battery | Turnigy nano-tech 5000mah 4S1P 65-130C | 1 | 576 | 576 | $76.59 | $76.59
TOTALS |  |  |  |  | Elective Mass: | 896 | Elective Price: | $227.47
 |  |  |  |  | Total Mass: | 1798 | Total Price: | $392.85
 |  |  |  |  | Total Pounds: | 3.96
5 | Multistar 3525-850
ITEM NO. | CATEGORY | PART NAME | PRODUCT NAME | QTY. | MASS EACH (g) | TOTAL MASS (g) | PRICE EACH | TOTAL PRICE
9 | Electronics | Motor | Multistar 3525-850 (3 cells) | 4 | 58 | 232 | $27.60 | $110.40
10 | Electronics | ESC | Tunigy Plush 25A Speed Controller (35A Burst) | 4 | 22 | 88 | $12.61 | $50.44
11 | Electronics | Battery | Turnigy nano-tech 5000mah 3S1P 65-130C | 1 | 442 | 442 | $57.44 | $57.44
TOTALS |  |  |  |  | Elective Mass: | 762 | Elective Price: | $218.28
 |  |  |  |  | Total Mass: | 1664 | Total Price: | $383.66
 |  |  |  |  | Total Pounds: | 3.67
6 | Multistar 4822-390
ITEM NO. | CATEGORY | PART NAME | PRODUCT NAME | QTY. | MASS EACH (g) | TOTAL MASS (g) | PRICE EACH | TOTAL PRICE
9 | Electronics | Motor | Multistar 4822-390 (6 cells) | 4 | 98 | 392 | $30.99 | $123.96
10 | Electronics | ESC | Tunigy Plush 40A Speed Controller (55A Burst) | 4 | 33 | 132 | $22.17 | $88.68
11 | Electronics | Battery | Turnigy nano-tech 5000mah 6S1P 45-90C | 1 | 813 | 813 | $94.81 | $94.81
TOTALS |  |  |  |  | Elective Mass: | 1337 | Elective Price: | $307.45
 |  |  |  |  | Total Mass: | 2239 | Total Price: | $472.83
 |  |  |  |  | Total Pounds: | 4.94
7 | Multistar 4822-490
ITEM NO. | CATEGORY | PART NAME | PRODUCT NAME | QTY. | MASS EACH (g) | TOTAL MASS (g) | PRICE EACH | TOTAL PRICE
9 | Electronics | Motor | Multistar 4822-490 (4-6 cells) | 4 | 98 | 392 | $30.99 | $123.96
10 | Electronics | ESC | Tunigy Plush 40A Speed Controller (55A Burst) | 4 | 33 | 132 | $22.17 | $88.68
11 | Electronics | Battery | Turnigy nano-tech 5000mah 4S1P 45-90C | 1 | 585 | 585 | $63.19 | $63.19
TOTALS |  |  |  |  | Elective Mass: | 1109 | Elective Price: | $275.83
 |  |  |  |  | Total Mass: | 2011 | Total Price: | $441.21
 |  |  |  |  | Total Pounds: | 4.43
8 | Multistar 4822-570
ITEM NO. | CATEGORY | PART NAME | PRODUCT NAME | QTY. | MASS EACH (g) | TOTAL MASS (g) | PRICE EACH | TOTAL PRICE
9 | Electronics | Motor | Multistar 4822-570 (4 cells) | 4 | 98 | 392 | $30.99 | $123.96
10 | Electronics | ESC | Tunigy Plush 25A Speed Controller (35A Burst) | 4 | 22 | 88 | $12.61 | $50.44
11 | Electronics | Battery | Turnigy nano-tech 5000mah 4S1P 65-130C | 1 | 576 | 576 | $76.59 | $76.59
TOTALS |  |  |  |  | Elective Mass: | 1056 | Elective Price: | $250.99
 |  |  |  |  | Total Mass: | 1958 | Total Price: | $416.37
 |  |  |  |  | Total Pounds: | 4.32
9 | Multistar 4822-690
ITEM NO. | CATEGORY | PART NAME | PRODUCT NAME | QTY. | MASS EACH (g) | TOTAL MASS (g) | PRICE EACH | TOTAL PRICE
9 | Electronics | Motor | Multistar 4822-690 (4 cells) | 4 | 95 | 380 | $30.99 | $123.96
10 | Electronics | ESC | Tunigy Plush 25A Speed Controller (35A Burst) | 4 | 22 | 88 | $12.61 | $50.44
11 | Electronics | Battery | Turnigy nano-tech 5000mah 4S1P 65-130C | 1 | 576 | 576 | $76.59 | $76.59
TOTALS |  |  |  |  | Elective Mass: | 1044 | Elective Price: | $250.99
 |  |  |  |  | Total Mass: | 1946 | Total Price: | $416.37
 |  |  |  |  | Total Pounds: | 4.29
10 | Multistar 4225-390
ITEM NO. | CATEGORY | PART NAME | PRODUCT NAME | QTY. | MASS EACH (g) | TOTAL MASS (g) | PRICE EACH | TOTAL PRICE
9 | Electronics | Motor | Multistar 4225-390 (6 cells) | 4 | 86 | 344 | $27.99 | $111.96
10 | Electronics | ESC | Tunigy Plush 40A Speed Controller (55A Burst) | 4 | 33 | 132 | $22.17 | $88.68
11 | Electronics | Battery | Turnigy nano-tech 5000mah 6S1P 45-90C | 1 | 813 | 813 | $94.81 | $94.81
TOTALS |  |  |  |  | Elective Mass: | 1289 | Elective Price: | $295.45
 |  |  |  |  | Total Mass: | 2191 | Total Price: | $460.83
 |  |  |  |  | Total Pounds: | 4.83
11 | Multistar 4225-610
ITEM NO. | CATEGORY | PART NAME | PRODUCT NAME | QTY. | MASS EACH (g) | TOTAL MASS (g) | PRICE EACH | TOTAL PRICE
9 | Electronics | Motor | Multistar 4225-610 (4 cells) | 4 | 86 | 344 | $27.99 | $111.96
10 | Electronics | ESC | Tunigy Plush 25A Speed Controller (35A Burst) | 4 | 22 | 88 | $12.61 | $50.44
11 | Electronics | Battery | Turnigy nano-tech 5000mah 4S1P 65-130C | 1 | 576 | 576 | $76.59 | $76.59
TOTALS |  |  |  |  | Elective Mass: | 1008 | Elective Price: | $238.99
 |  |  |  |  | Total Mass: | 1910 | Total Price: | $404.37
 |  |  |  |  | Total Pounds: | 4.21

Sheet: Custom QRM
ITEM NO. | CATEGORY | PART NAME | DESCRIPTION | QTY. | MASS EACH (g) | TOTAL MASS (g) | PRICE EACH | TOTAL PRICE
1 | Frame | QRM001 | Bottom Arm | 4 | 4 | 16 | $5.00 | $20.00
2 | Frame | QRM002 | Top Arm | 2 | 4 | 8 | $5.00 | $10.00
3 | Frame | QRM003 | Battery Tray | 1 | 10 | 10 | $5.00 | $5.00
4 | Frame | QRM004 | Bottom Frame Ring | 1 | 4 | 4 | $5.00 | $5.00
5 | Frame | QRM005 | Top Frame Ring | 1 | 4 | 4 | $5.00 | $5.00
6 | Frame | QRM006 | Electronic Cover | 1 | 3 | 3 | $5.00 | $5.00
7 | Electronics | Control Board | KK2.0 Multi-rotor LCD Flight Controller | 1 | 21 | 21 | $29.99 | $29.99
8 | Electronics | Motor | Turnigy 1811-2000 Brushless Outrunner | 4 | 11 | 44 | $9.75 | $39.00
9 | Electronics | ESC | Tunigy Plush 6A Speed Controller (8A Burst) | 4 | 6 | 24 | $7.98 | $31.92
10 | Electronics | Battery | ZIPPY Flightmax 800mAh 2S1P 20C | 1 | 49 | 49 | $5.50 | $5.50
11 | Electronics | Low Voltage Alarm | On-Board Lipoly Low Voltage Alarm 2s~3s | 1 | 5 | 5 | $1.99 | $1.99
12 | Electronics | Receiver | Spektrum AR400 DSMX 4 Channel Receiver | 1 | 12.67 | 12.67 | $29.99 | $29.99
 | Electronics | Hub | Power Distribution Board | 1
13 | Hardware | QRM101 | 6mm Frame Spacer | 4 | 0.14 | 0.56 | $0.09 | $0.37
14 | Hardware | QRM103 | 15mm Frame Spacer | 4 | 0.34 | 1.36 | $0.22 | $0.87
15 | Hardware | QRM104 | 10mm Threaded Frame Spacer | 32 | 0.23 | 7.36 | $0.09 | $2.94
16 | Hardware | 6mm Hex Screw | M3X6 | 20 | 0.61 | 12.2 | $0.21 | $4.20
17 | Hardware | 16mm Hex Screw | M3X16 | 20 | 1.08 | 21.6 | $0.10 | $1.95
18 | Hardware | 6mm Hex Screw | M2X6 | 16 | 0.22 | 3.52 | $0.10 | $1.55
19 | Hardware | 2mm Hex Nut | M2 Nylon Lock Nut | 16 | 0.16 | 2.56 | $0.08 | $1.26
20 | Hardware | Propeller - Right | 6X3 - Standard Rotating | 2 | 2.36 | 4.72 | $0.50 | $1.00
21 | Hardware | Propeller - Left | 6X3 - Counter Rotating | 2 | 2.36 | 4.72 | $0.50 | $1.00
22 | Hardware | Prop Adapter A | Prop Saver & O-Ring | 4 | 1.13 | 4.52 | $0.00 | $0.00
23 | Hardware | Prop Adapter B | Nose Cone | 0 | 2.74 | 10.96 | $0.00 | $0.00
24 | Hardware | Miscellaneous | Electrical Tape, Solder, Cable Ties, Etc. | 1 | 0 | 0 | $0.00 | $0.00
TOTALS |  |  | Total Number of Parts: | 144 | Total Mass: | 274.75 | Total Price: | $203.54
 |  |  |  |  |  |  |  | 2014-03-30

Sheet: Prop Clearance
Octocopter Prop Clearance
Prop Diameter (in) | Motor to Motor Distance (mm) | Prop Clearance (mm) | Side Length (mm) |  | Area (in^) | Prop to Unit Area Ratio
5 | 398.2 | 25.38454277
5 |  | -127
5
5
5 |  | 1289.155039
5
5
5
5
5
Hexacopter
Prop Diameter (in) | Motor to Motor Distance (in) | Prop Clearance (in) | Side Length (in) | Prop Area (sq ft) | Unit Area (sq ft) | Prop to Unit Area Ratio
5 | 10 | 0.0 | 7.89 | 0.82 | 1.12 | 72.90091123%
5 | 11 | 0.5 | 8.39 | 0.82 | 1.27 | 64.46763226%
5 | 12 | 1.0 | 8.89 | 0.82 | 1.42 | 57.4173569%
5 | 13 | 1.5 | 9.39 | 0.82 | 1.59 | 51.46341798%
5 | 14 | 2.0 | 9.89 | 0.82 | 1.76 | 46.38974985%
5 | 15 | 2.5 | 10.39 | 0.82 | 1.95 | 42.03100593%
5 | 16 | 3.0 | 10.89 | 0.82 | 2.14 | 38.25891474%
5 | 17 | 3.5 | 11.39 | 0.82 | 2.34 | 34.97273362%
5 | 18 | 4.0 | 11.89 | 0.82 | 2.55 | 32.09245183%
5 | 19 | 4.5 | 12.39 | 0.82 | 2.77 | 29.55387383%
5 | 20 | 5.0 | 12.89 | 0.82 | 3.00 | 27.30501104%
6 | 12 | 0.0 | 9.46 | 1.18 | 1.62 | 72.90091123%
6 | 13 | 0.5 | 9.96 | 1.18 | 1.79 | 65.76812344%
6 | 14 | 1.0 | 10.46 | 1.18 | 1.98 | 59.63316355%
6 | 15 | 1.5 | 10.96 | 1.18 | 2.17 | 54.31823407%
6 | 16 | 2.0 | 11.46 | 1.18 | 2.37 | 49.68344392%
6 | 17 | 2.5 | 11.96 | 1.18 | 2.58 | 45.61750834%
6 | 18 | 3.0 | 12.46 | 1.18 | 2.80 | 42.03100593%
6 | 19 | 3.5 | 12.96 | 1.18 | 3.03 | 38.85141969%
6 | 20 | 4.0 | 13.46 | 1.18 | 3.27 | 36.01944235%
6 | 21 | 4.5 | 13.96 | 1.18 | 3.52 | 33.48619062%
6 | 22 | 5.0 | 14.46 | 1.18 | 3.77 | 31.2110815%
6 | 23 | 5.5 | 14.96 | 1.18 | 4.04 | 29.16019667%
6 | 24 | 6.0 | 15.46 | 1.18 | 4.31 | 27.30501104%
7 | 14 | 0.0 | 11.04 | 1.60 | 2.20 | 72.90091123%
7 | 15 | 0.5 | 11.54 | 1.60 | 2.40 | 66.72129003%
7 | 16 | 1.0 | 12.04 | 1.60 | 2.62 | 61.29536226%
7 | 17 | 1.5 | 12.54 | 1.60 | 2.84 | 56.50536606%
7 | 18 | 2.0 | 13.04 | 1.60 | 3.07 | 52.25567218%
7 | 19 | 2.5 | 13.54 | 1.60 | 3.31 | 48.46797369%
7 | 20 | 3.0 | 14.04 | 1.60 | 3.56 | 45.07765269%
7 | 21 | 3.5 | 14.54 | 1.60 | 3.82 | 42.03100593%
7 | 22 | 4.0 | 15.04 | 1.60 | 4.08 | 39.283105%
7 | 23 | 4.5 | 15.54 | 1.60 | 4.36 | 36.79613037%
7 | 24 | 5.0 | 16.04 | 1.60 | 4.64 | 34.53806316%
7 | 25 | 5.5 | 16.54 | 1.60 | 4.94 | 32.48164933%
7 | 26 | 6.0 | 17.04 | 1.60 | 5.24 | 30.60357344%
7 | 27 | 6.5 | 17.54 | 1.60 | 5.55 | 28.88379489%
7 | 28 | 7.0 | 18.04 | 1.60 | 5.87 | 27.30501104%
8 | 16 | 0.0 | 12.62 | 2.09 | 2.87 | 72.90091123%
8 | 17 | 0.5 | 13.12 | 2.09 | 3.11 | 67.44982922%
8 | 18 | 1.0 | 13.62 | 2.09 | 3.35 | 62.58804669%
8 | 19 | 1.5 | 14.12 | 2.09 | 3.60 | 58.23358328%
8 | 20 | 2.0 | 14.62 | 2.09 | 3.86 | 54.31823407%
8 | 21 | 2.5 | 15.12 | 2.09 | 4.12 | 50.78488246%
8 | 22 | 3.0 | 15.62 | 2.09 | 4.40 | 47.58540523%
8 | 23 | 3.5 | 16.12 | 2.09 | 4.69 | 44.67902528%
8 | 24 | 4.0 | 16.62 | 2.09 | 4.98 | 42.03100593%
8 | 25 | 4.5 | 17.12 | 2.09 | 5.29 | 39.61160812%
8 | 26 | 5.0 | 17.62 | 2.09 | 5.60 | 37.39525179%
8 | 27 | 5.5 | 18.12 | 2.09 | 5.92 | 35.35983695%
8 | 28 | 6.0 | 18.62 | 2.09 | 6.25 | 33.48619062%
8 | 29 | 6.5 | 19.12 | 2.09 | 6.59 | 31.75761367%
8 | 30 | 7.0 | 19.62 | 2.09 | 6.94 | 30.15950743%
8 | 31 | 7.5 | 20.12 | 2.09 | 7.30 | 28.67906443%
8 | 32 | 8.0 | 20.62 | 2.09 | 7.67 | 27.30501104%
10 | 20 | 0.0 | 15.77 | 3.27 | 4.49 | 72.90091123%
10 | 21 | 0.5 | 16.27 | 3.27 | 4.78 | 68.48999983%
10 | 22 | 1.0 | 16.77 | 3.27 | 5.08 | 64.46763226%
10 | 23 | 1.5 | 17.27 | 3.27 | 5.38 | 60.78947901%
10 | 24 | 2.0 | 17.77 | 3.27 | 5.70 | 57.4173569%
10 | 25 | 2.5 | 18.27 | 3.27 | 6.02 | 54.31823407%
10 | 26 | 3.0 | 18.77 | 3.27 | 6.36 | 51.46341798%
10 | 27 | 3.5 | 19.27 | 3.27 | 6.70 | 48.82788889%
10 | 28 | 4.0 | 19.77 | 3.27 | 7.05 | 46.38974985%
10 | 29 | 4.5 | 20.27 | 3.27 | 7.42 | 44.12977033%
10 | 30 | 5.0 | 20.77 | 3.27 | 7.79 | 42.03100593%
10 | 31 | 5.5 | 21.27 | 3.27 | 8.17 | 40.07847981%
10 | 32 | 6.0 | 21.77 | 3.27 | 8.55 | 38.25891474%
10 | 33 | 6.5 | 22.27 | 3.27 | 8.95 | 36.56050684%
10 | 34 | 7.0 | 22.77 | 3.27 | 9.36 | 34.97273362%
10 | 35 | 7.5 | 23.27 | 3.27 | 9.77 | 33.48619062%
10 | 36 | 8.0 | 23.77 | 3.27 | 10.20 | 32.09245183%
10 | 37 | 8.5 | 24.27 | 3.27 | 10.63 | 30.78395003%
10 | 38 | 9.0 | 24.77 | 3.27 | 11.07 | 29.55387383%
10 | 39 | 9.5 | 25.27 | 3.27 | 11.52 | 28.39607889%
10 | 40 | 10.0 | 25.77 | 3.27 | 11.98 | 27.30501104%

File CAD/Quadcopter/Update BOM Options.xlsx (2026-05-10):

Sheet: Motors
Option | Brand | Line | Model | Lipo Cells | KV (rpm/v) | No Load Current (Amps) | Max Watts | Operating Current (Amps) | Max Current (Amps) | Internal Resistance (ohm) | Number of Poles | Shaft Size (mm) | Diameter (mm) | Case Length (mm) | Mass (grams) | Recommended ESC (Amp Rating) | Price (US$) | Link
1 | Turnigy | Aerodrive SK3 | 3530-1150 | 3-4 | 1150 |  | 330 | ? | 24 | 0.069 | 28 | 4 | 37 | 31 | 76 | 30 | $25.01 | Link (http://www.hobbyking.com/hobbyking/store/__18160__Turnigy_Aerodrive_SK3_3530_1150kv_Brushless_Outrunner_Motor.html)
2 | Turnigy | Multistar | 3525-650 | 4 | 650 | 0.50 | 250 | 14 | 17 | 0.178 | 14 | 4 | 35 | 25.0 | 58 | 25 | $25.11 | Link (http://www.hobbyking.com/hobbyking/store/__36765__Turnigy_Multistar_3525_650Kv_14Pole_Multi_Rotor_Outrunner.html)
3 | Turnigy | Multistar | 3525-850 | 3 | 850 | 0.60 | 250 | 19 | 23 | 0.101 | 14 | 4 | 35 | 25.0 | 58 | 25 | $27.60 | Link (http://www.hobbyking.com/hobbyking/store/__36767__Turnigy_Multistar_3525_850Kv_14Pole_Multi_Rotor_Outrunner.html)
4 | Turnigy | Multistar | 4225-610 | 4 | 610 | 0.30 | 330 | 16 | 22 | 0.091 | 16 | 6 | 42 | 24.5 | 86 | 25 | $27.99 | Link (http://www.hobbyking.com/hobbyking/store/__26964__Turnigy_Multistar_4225_610Kv_16Pole_Multi_Rotor_Outrunner.html)
 |  |  |  |  |  |  |  |  |  |  |  |  |  |  | 2013-08-19 22:21

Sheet: BOM Calculator
DETERMINED PARTS |  |  |  |  |  |  | 2013-08-19 22:21
ITEM NO. | CATEGORY | PART NAME | PART SPECS | QTY. | MASS EACH (g) | TOTAL MASS (g) | PRICE EACH | TOTAL PRICE
1 | Frame | Quadcopter | Turnigy Talon Quadcopter V2.0 (without landing feet) | 1 | 242 | 242 | $56.39 | $56.39
2 | Electronics | Control Board | KK2.0 Multi-rotor LCD Flight Controller | 1 | 18 | 18 | $29.99 | $29.99
3 | Electronics | Receiver | Turnigy 9X 2.4GHz 8Ch Receiver (V2) | 1 | 18 | 18 | $9.11 | $9.11
4 | Hardware | Miscellaneous | Electrical Tape, Solder, Cable Ties, Etc. | 1 | 10 | 10 | $0.00 | $0.00
5 | Accessories | Gimbal | Arris CM2000 | 1 | 195 | 195 | $0.00 | $0.00
6 | Accessories | Camera | Gopro Hero 3 - Black Edition | 1 | 75 | 75 | $0.00 | $0.00
7 | Frame | Landing Gear | ATG Carbon Fiber Landing Skid Kit | 1 | 284 | 284 | $45.89 | $45.89
8 | Hardware | Propellers | 12x6 Carbon Fiber Propellers | 4 | 15 | 60 | $6.00 | $24.00
TOTALS |  |  | Determined Parts: | 11 | Determined Mass: | 902 | Determined Price: | $165.38
ELECTIVE PARTS
1 | Aerodrive SK3-3530-1150
ITEM NO. | CATEGORY | PART NAME | PRODUCT NAME | QTY. | MASS EACH (g) | TOTAL MASS (g) | PRICE EACH | TOTAL PRICE
9 | Electronics | Motor | Aerodrive SK3-3530-1150 (3 cells) | 4 | 76 | 304 | $25.01 | $100.04
10 | Electronics | ESC | Tunigy Plush 25A Speed Controller (35A Burst) | 4 | 22 | 88 | $12.61 | $50.44
11 | Electronics | Battery | Turnigy nano-tech 5000mah 3S1P 45C | 1 | 462 | 462 | $38.81 | $38.81
TOTALS |  |  |  |  | Elective Mass: | 854 | Elective Price: | $189.29
 |  |  |  |  | Total Mass: | 1756 | Total Price: | $354.67
 |  |  |  |  | Total Pounds: | 3.87
2 | Multistar 3525-650
ITEM NO. | CATEGORY | PART NAME | PRODUCT NAME | QTY. | MASS EACH (g) | TOTAL MASS (g) | PRICE EACH | TOTAL PRICE
9 | Electronics | Motor | Multistar 3525-650 (4 cells) | 4 | 58 | 232 | $25.11 | $100.44
10 | Electronics | ESC | Tunigy Plush 25A Speed Controller (35A Burst) | 4 | 22 | 88 | $12.61 | $50.44
11 | Electronics | Battery | Turnigy nano-tech 5000mah 4S1P 65-130C | 1 | 576 | 576 | $76.59 | $76.59
TOTALS |  |  |  |  | Elective Mass: | 896 | Elective Price: | $227.47
 |  |  |  |  | Total Mass: | 1798 | Total Price: | $392.85
 |  |  |  |  | Total Pounds: | 3.96
3 | Multistar 3525-850
ITEM NO. | CATEGORY | PART NAME | PRODUCT NAME | QTY. | MASS EACH (g) | TOTAL MASS (g) | PRICE EACH | TOTAL PRICE
9 | Electronics | Motor | Multistar 3525-850 (3 cells) | 4 | 58 | 232 | $27.60 | $110.40
10 | Electronics | ESC | Tunigy Plush 25A Speed Controller (35A Burst) | 4 | 22 | 88 | $12.61 | $50.44
11 | Electronics | Battery | Turnigy nano-tech 5000mah 3S1P 65-130C | 1 | 442 | 442 | $57.44 | $57.44
TOTALS |  |  |  |  | Elective Mass: | 762 | Elective Price: | $218.28
 |  |  |  |  | Total Mass: | 1664 | Total Price: | $383.66
 |  |  |  |  | Total Pounds: | 3.67
4 | Multistar 4225-610
ITEM NO. | CATEGORY | PART NAME | PRODUCT NAME | QTY. | MASS EACH (g) | TOTAL MASS (g) | PRICE EACH | TOTAL PRICE
9 | Electronics | Motor | Multistar 4225-610 (4 cells) | 4 | 86 | 344 | $27.99 | $111.96
10 | Electronics | ESC | Q Brain 4x20A Brushless Quadcopter ESC | 1 | 112 | 112 | $28.53 | $28.53
11 | Electronics | Battery | Turnigy nano-tech 5000mah 4S1P 65-130C | 1 | 576 | 576 | $76.59 | $76.59
TOTALS |  |  |  |  | Elective Mass: | 1032 | Elective Price: | $217.08
 |  |  |  |  | Total Mass: | 1934 | Total Price: | $382.46
 |  |  |  |  | Total Pounds: | 4.26

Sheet: Final BOM
DETERMINED PARTS |  |  |  |  |  |  | 2013-08-19 22:21
ITEM NO. | CATEGORY | PART NAME | PART SPECS | QTY. | MASS EACH (g) | TOTAL MASS (g) | PRICE EACH | TOTAL PRICE
1 | Frame | Quadcopter | Turnigy Talon Quadcopter V2.0 (sans landing feet) | 1 | 242 | 242 | $56.39 | $56.39
2 | Electronics | Control Board | KK2.0 Multi-rotor LCD Flight Controller | 1 | 18 | 18 | $29.99 | $29.99
3 | Electronics | Receiver | Turnigy 9X 2.4GHz 8Ch Receiver (V2) | 1 | 18 | 18 | $9.11 | $9.11
4 | Hardware | Miscellaneous | Electrical Tape, Solder, Cable Ties, Etc. | 1 | 10 | 10 | $0.00 | $0.00
7 | Frame | Landing Gear | ATG Carbon Fiber Landing Skid Kit | 1 | 284 | 284 | $45.89 | $45.89
8 | Hardware | Propellers | 11x4.7 Slow Fly Electric Propellers | 4 | 15 | 60 | $6.00 | $24.00
TOTALS |  |  | Determined Parts: | 9 | Determined Mass: | 632 | Determined Price: | $165.38
ELECTIVE PARTS
ITEM NO. | CATEGORY | PART NAME | PRODUCT NAME | QTY. | MASS EACH (g) | TOTAL MASS (g) | PRICE EACH | TOTAL PRICE
9 | Electronics | Motor | Multistar 4225-610 (4 cells) | 4 | 86 | 344 | $27.99 | $111.96
10 | Electronics | ESC | Q Brain 4x20A Brushless Quadcopter ESC | 1 | 112 | 112 | $28.53 | $28.53
11 | Electronics | Battery | Turnigy nano-tech 5000mah 4S1P 65-130C | 1 | 578 | 578 | $76.59 | $76.59
TOTALS |  |  | Elective Parts: | 6 | Elective Mass: | 1034 | Elective Price: | $217.08
AERIAL PHOTOGRAPHY ACCESSORIES
ITEM NO. | CATEGORY | PART NAME | PRODUCT NAME | QTY. | MASS EACH (g) | TOTAL MASS (g) | PRICE EACH | TOTAL PRICE
12 | Accessories | Gimbal | Arris CM2000 Brushless Motor Gimbal V4.0 | 1 | 240 | 240 | $309.00 | $309.00
13 | Accessories | Battery | Turnigy nano-tech 850mah 3S1P 25-40C | 1 | 69 | 69 | $7.19 | $7.19
14 | Accessories | Camera | Gopro Hero 3 - Black Edition | 1 | 75 | 75 | $399.00 | $399.00
TOTALS |  |  | Accessories Parts: | 3 | Accessories Mass: | 384 | Accessories Price: | $715.19
 |  |  |  |  | Sans Accessories Mass: | 1666 | Sans Accessories Price: | $382.46
 |  |  |  |  | Total Mass: | 2050 | Total Price: | $1097.65
 |  |  |  |  | Imperial (lbs): | 4.52

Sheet: Scorecard
Elective BOM Option | Motor Model | Hover Flight Time (minutes) | Hover Score | Weight (grams) | Weight Score | Additional Payload (grams) | Additional Payload Score | Throttle at Hover (%) | Throttle At Hover Score | Recommended Props | Prop Score | Total Score (higher is better) | Weighted Total Score Option 1 | Weighted Total Score Option 2 | ecalc Link
2 | 3525-650 | 15.9 | 4 | 1798 | 2 | 855 | 1 | 53 | 1 | 10x4.7 - 11x4.7 | 3 | 11 | 37 | 22.5 | Link (http://www.ecalc.ch/xcoptercalc.htm?ecalc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)
1 | 3530-1150 | 13.2 | 1 | 1756 | 3 | 2165 | 4 | 31 | 4 | 8x5 - 11x4.7 | 1 | 13 | 36 | 24 | Link (http://www.ecalc.ch/xcoptercalc.htm?ecalc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)
3 | 3525-850 | 13.4 | 2 | 1664 | 4 | 880 | 2 | 51 | 2 | 10x4.7 - 11x4.7 | 3 | 13 | 38 | 24 | Link (http://www.ecalc.ch/xcoptercalc.htm?ecalc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)
4 | 4225-610 | 15.4 | 3 | 1910 | 1 | 1791 | 3 | 37 | 3 | 12x3 - 12x6 | 4 | 14 | 41 | 25.5 | Link (http://www.ecalc.ch/xcoptercalc.htm?ecalc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)
 |  |  |  |  |  |  |  |  |  |  |  | 2013-08-19 22:21

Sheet: Summary of Scores
Rank Worst to Best | No Weight | Weight Option 1 | Weight Option 2
4 | 3525-650 | 3530-1150 | 3525-650
3 | 3530-1150 | 3525-650 | 3530-1150
2 | 3525-850 | 3525-850 | 3525-850
1 | 4225-610 | 4225-610 | 4225-610
 |  |  | 2013-08-19 22:21

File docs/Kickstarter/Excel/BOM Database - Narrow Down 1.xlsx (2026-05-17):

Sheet: BOM Summary
 |  |  |  |  |  |  |  | 2014-04-09 13:18
ITEM NO. | CATEGORY | COMPONENT | BRAND | DROP DOWNS: | QTY. | MASS EACH (g) | TOTAL MASS (g) | PRICE EACH | TOTAL PRICE
1 | Hardware | Multirotor | Carboncore | Hex 950 | 1 | 780 | 780 | $590 | $590
2 | Electronics | Flight Contoller | DJI | Naza-M V2 | 1 | 95 | 95 | $299 | $299
3 | Electronics | Transmitter | Futaba | 8FG Super | 1 | 0 | 0 | $479 | $479
4 | Electronics | Receiver | Futaba | R6208SB | 1 | 13.8 | 13.8 | $129.99 | $129.99
5 | Electronics | Camera | GoPro | Hero 3+ Black | 1 | 74 | 74 | $399.99 | $399.99
6 | Electronics | Gimbal | DJI | H3-3D | 1 | 168 | 168 | $500 | $500
7 | Electronics | Motor | Tiger | U5-400 | 6 | 156 | 936 | $125.9 | $755.4
8 | Electronics | ESC | Maytech | MT 40 | 6 | 35 | 210 | $37 | $222
9 | Electronics | Battery | ADC | 5000mAh 6S 40C | 2 | 790 | 1580 | $189 | $378
10 | Hardware | Propellers | GemFan | 15x5.5 | 5 | 16.4 | 98.4 | $40 | $200
11 | Hardware | Accessories | Spot | Trace | 1 | 88 | 88 | $199.84 | $199.84
TOTALS |  |  |  | # of Parts: | 14 | Mass: | 4043.2 | Price: | $4153.22
 |  |  |  |  |  |  |  | Less what I already own: | $3274.23
 |  |  |  |  |  |  | Selected during:
ITEM NO. | CATEGORY | COMPONENT | OPTIONS |  |  |  | Round 1
1 | Hardware | Multirotor | 9
2 | Electronics | Flight Contoller | 5
3 | Electronics | Transmitter | 1 |  | rr
4 | Electronics | Receiver | 1
5 | Accessories | Camera | 1
6 | Accessories | Gimbal | 5
7 | Electronics | Motor | 20
8 | Electronics | ESC | 23
9 | Electronics | Battery | 17
10 | Hardware | Propellers | 28
11 | Accessories | GPS Tracker | 1
 |  | # OF TOTAL POSSIBLE COMBINATIONS: | 49266000
 |  |  |  | Round 1 | Round 2 | Round 3
ITEM NO. | CATEGORY | COMPONENT | OPTIONS | 4/5/14 11:15AM
1 | Frame | Multirotor | 21 | 9
2 | Electronics | Flight Contoller | 7 | 5
3 | Electronics | Transmitter | 13 | 1 | 1 | 1
4 | Electronics | Receiver | 8 | 1 | 1 | 1
5 | Accessories | Camera | 7 | 1 | 1 | 1
6 | Accessories | Gimbal | 7 | 5
7 | Electronics | Motor | 37 | 20
8 | Electronics | ESC | 23 | 23
9 | Electronics | Battery | 17 | 17
10 | Hardware | Propellers | 28 | 28
11 | Accessories | GPS Tracker | 1 | 1 | 1 | 1
 |  | # OF TOTAL POSSIBLE COMBINATIONS: | 303447292512 | 49266000 | 0
 |  |  | % reduction | 99.98
 | dd

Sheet: 1. Multirotor Frames
Multirotor Frames
Option | Brand | Line | Model | # of Motors | Frame Mass (g) | Between Motor Centers (mm) | Between Motor Centers (in) | Material | Country of Origin | Retractable Landing Gear Option? | Max Propeller Size | Foldable? | Stock Frame Fits Gimbal? | Payload Limit (KG) | Price (US$) | Link
 | Aeronavics | Airframe | XM-6 Ti-QR | 6 | ? | 770 | 30.3 | CF | New Zealand | Y | 14 | Y | Y | ? | $1922.69 | www.aeronavics.com (http://aeronavics.com/products/shop/xm-airframe-kits/airframe-xm-6-ti-qr/)
 | Aeronavics | Airframe | XM-8 Ti-QR | 8 | 2415 | 940 | 37.0 | CF | New Zealand | Y | 13 | Y | Y | ? | $2091.57 | www.aeronavics.com (http://aeronavics.com/products/shop/xm-airframe-kits/airframe-xm-8-ti-qr/)
 | Aeronavics | SkyJib | 6 Ti-QR | 6 | ? | 1080 | 42.5 | CF | New Zealand | Y | 17 | Y | Y | ? | $2684.83 | www.aeronavics.com (http://aeronavics.com/products/shop/skyjib-airframe-kits/airframe-skyjib-super-6-ti-qr/)
 | Aeronavics | SkyJib | 8 Ti-QR | 8 | ? | 1160 | 45.7 | CF | New Zealand | Y | 15 | Y | Y | ? | $3057.25 | www.aeronavics.com (http://aeronavics.com/products/shop/skyjib-airframe-kits/airframe-skyjib-8-ti-qr/)
 | Aeronavics | SkyJib | X4 Ti-QR | 8 | ? | 900 | 35.4 | CF | New Zealand | Y | 15 | Y | Y | ? | $2702.15 | www.aeronavics.com (http://aeronavics.com/products/shop/skyjib-airframe-kits/airframe-skyjib-x4-ti-qr/)
1 | Arris | Hexacopter | M1000 | 6 | ? | 1000 | 39.4 | CF | China | N | ? | N | Y | ? | $350.00 | www.hobby-wing.com (http://hobby-wing.com/hobby-wing-arris-4-6-rotor-multicopter-frame.html) | remove because M1050 is better
2 | Arris | Hexacopter | M1050 | 6 | 1400 | 1050 | 41.3 | CF | China | N | 17 | Y | Y | ? | $349.00 | www.hobby-wing.com (http://hobby-wing.com/arris-m1050-foldable-quadcopter-frame.html)
 | Arris | Hexacopter | M680 | 6 | ? | 680 | 26.8 | CF | China | N | ? | Y | Y | ? | $195.00 | www.hobby-wing.com (http://hobby-wing.com/arris-m680-foldable-quadcopter-frame.html)
3 | Carboncore | Hexacopter | Hex 650 | 6 | 720 | 650 | 25.6 | CF | United Kingdom | N | ? | N | Y | 6 total | $549.00 | www.coptersquad.com (http://www.coptersquad.com/en/carboncore-h650-hexacopter-frame.html)
4 | Carboncore | Hexacopter | Hex 950 | 6 | 780 | 950 | 37.4 | CF | United Kingdom | N | ? | N | Y | 8 total | $590.00 | www.coptersquad.com (http://www.coptersquad.com/en/carboncore-multicopter-h950-carboncore-hexacopter.html)
 | Carboncore | Octocopter | X8 650 Quad | 8 | 600 | 650 | 25.6 | CF | United Kingdom | N | ? | N | N | ? | $385.00 | www.rc-drones.com (http://www.rc-drones.com/carboncore-X8-650-Quadcopter.php)
5 | Carboncore | Octocopter | X8 950 Quad | 8 | 655 | 950 | 37.4 | CF | United Kingdom | N | ? | N | N | ? | $435.00 | www.rc-drones.com (http://www.rc-drones.com/carboncore-X8-950-Quadcopter.php)
 | Carboncore | X8 Co-Axial | Cortex | 8 | 1230 | 800 | 31.5 | CF | United Kingdom | N | ? | Y | Y | ? | $1100.00 | www.shop.carboncore.co.uk
 | DJI | Spreading Wings | S1000 | 8 | 4200 | 1000 | 39.4 | CF | China | Y | 15 | Y | Y | 5.8 | $3939.00 | www.dji.com (http://www.dji.com/product/spreading-wings-s1000)
 | DJI | Spreading Wings | S800 EVO | 6 | 3700 | 800 | 31.5 | CF | China | Y | 15 | N | Y | 4.3 | $2999.00 | www.dji.com (http://www.dji.com/product/spreading-wings-s800-evo)
6 | Tarot | Hexacopter | TL810A | 6 | 1020 | 850 | 33.5 | CF | China | N | 15 | Y | Y | 3.0 | $339.00 | s (http://www.myrcmodel.com/index.php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)
7 | Tarot | Hexacopter | TL960A | 6 | 1050 | 960 | 37.8 | CF | China | N | 15 | Y | Y | 3.5 | $339.00 | www.myrcmodel.com (http://www.myrcmodel.com/index.php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)
8 | Tarot | Octocopter | T15 | 8 | 1950 | 1020 | 40.2 | CF | China | N | 15 | Y | Y | 11 total | $619.00 | www.myrcmodel.com (http://www.myrcmodel.com/index.php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)
 | Tarot | Hexacopter | FY680 | 6 | 600 | 680 | 26.8 | CF | China | N | 13 | Y | Y | ? | $169.99 | www.myrcmodel.com (http://www.myrcmodel.com/index.php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)
 | Tarot | Hexacopter | FY690S | 6 | 600 | 690 | 27.2 | CF | China | N | 13 | Y | Y | ? | $199.00 | www.myrcmodel.com (http://www.myrcmodel.com/index.php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)
9 | Tarot | Octocopter | IRON MAN 1000 | 8 | 1500 | 1020 | 40.2 | CF | China | N | 15 | N | Y | 8.0 | $399.00 | www.myrcmodel.com (http://www.myrcmodel.com/index.php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)
 |  |  |  | Minimums: | 600 | 650 | 25.59055118 |  |  |  | 13 |  |  |  | $169.99 | 2014-04-09 13:18
 |  |  |  | Maximums: | 4200 | 1160 | 45.66929134 |  |  |  | 17 |  |  |  | $619.00
 |  |  |  | Averages: | 1494.666667 | 885.7142857 | 34.87064117 |  |  |  | 14.78571429 |  |  |  | $378.31
 | Round 1:
 | High Price
 | Small Size

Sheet: 2. Flight Controllers
Flight Controllers
Option | Brand | Model | GPS included? | LED included? | Gimbal Compatible? | Program via computer? | # of Battery Cells: | Mass (g) | Price (US$) | Link
1 | 3DRobotics | APM 2.6 Set | ? | N | Y | ? | ? | 0 | $239.98 | https://store.3drobotics.com (https://store.3drobotics.com/products/apm-2-6-kit-1)
2 | 3DRobotics | Pixhawk | ? | N | Y | ? | ? | 38 | $199.99 | https://store.3drobotics.com (https://store.3drobotics.com/products/3dr-pixhawk)
 | DJI | A2 | Y | Y | Y | Y | 2 - 6 | 224 | $1299.00 | http://www.dji.com/product/a2
3 | DJI | Naza-M V2 | Y | Y | Y | Y | 2 - 6 | 95 | $299.00 | http://www.dji.com/product/naza-m-v2
 | DJI | Wookong-M | Y | ? | Y | Y | 2 - 6 | 118 | $999.00 | http://www.dji.com/product/wookong-m
4 | Feiyu Tech | FY41AP GPS & OSD | Y | N | Y | Y | 2 - 6 | 220 | $412.00 | http://www.coptersquad.com (http://www.coptersquad.com/en/feiyu-tech-fy41ap-autopilot-gps-osd.html)
5 | Feiyu Tech | FYDosAutopilot | ? | N | Y | Y |  | 220 | $275.00 | http://www.coptersquad.com (http://www.coptersquad.com/en/feiyu-tech-fydosautopilot.html)
 |  |  |  |  |  |  | Min: | 0 | $199.99 | 2014-04-09 13:18
 |  |  |  |  |  |  | Max: | 224 | $1299.00
 |  |  |  |  |  |  | Avg: | 130.7142857 | $532.00
 | Round 1:
 | High Price

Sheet: 3. Transmitters
Transmitters
Option | Brand | Model | Radio Spectrum | # of Channels | Memory Card? | Type | Mode 2 available? | Recommened Receiver | LCD Screen? | Price | Link
13 | Futaba | 14SG | 2.4GHz | 14 | SD | FASST | Y | R6014HS | Y | $599.00 | http://www.futaba-rc.com/systems/futk9410-14sg/index.html
1 | Futaba | 8FG Super | 2.4GHz | 14 | SD | FASST | Y | R6208SB | Y | $479.00 | http://www.futaba-rc.com/systems/futk8010.html
 | Futaba | 10CG | 2.4GHz | 10 | ? | FASST | Y | R6014HS | Y | $549.90 | http://www.futaba-rc.com/systems/futk9255.html
 | Futaba | 7C | 2.4GHz | 7 | None | FASST | Y | R617FS | Y | $279.99 | http://www.futaba-rc.com/systems/futk7000.html
 | Futaba | 6EX | 2.4GHz | 6 | None | FASST | Y | R617FS | Y | $212.08 | http://www.futaba-rc.com/systems/futk6900.html
 | JR | XG14 | 2.4GHz | 14 | SD | DMSS | Y | RG1131B | Y | $679.00 | http://www.jramericas.com/233795/JRP00632/?pcat=2
 | JR | XG11 | 2.4GHz | 11 | SD | DMSS | Y | RG1131B | Y | $799.00 | http://www.jramericas.com/211277/JRP00615/?pcat=2
 | JR | XG8 | 2.4GHz | 8 | SD | DMSS | Y | RG731B | Y | $429.00 | http://www.jramericas.com/211276/JRP00596/?pcat=2
 | JR | XG6 | 2.4GHz | 6 | microSD | DMSS | Y | RG631B | Y | $199.00 | http://www.jramericas.com/211278/JRP00619/?pcat=2
 | Spektrum | DX9 | 2.4GHz | 9 | SD | DSM2/DSMX | Y | ? | Y | $449.99 | http://www.spektrumrc.com/Products/Default.aspx?ProdId=SPMR9900
 | Spektrum | DX8 | 2.4GHz | 8 | SD | DSM2/DSMX | Y | ? | Y | $299.99 | http://www.spektrumrc.com/Products/Default.aspx?ProdId=SPMR8810
 | Spektrum | DX7s | 2.4GHz | 7 | SD | DSM2/DSMX | Y | AR8000 | Y | $299.99 | http://www.spektrumrc.com/Products/Default.aspx?ProdId=SPM7800
1 | Spektrum | DX6 | 2.4GHz | 6 | SD | DSM2/DSMX | Y | AR610 | Y | $229.99 | http://www.spektrumrc.com/Products/Default.aspx?ProdId=SPM6700
 |  | Min: |  | 6 |  |  |  |  |  | $199.00 | 2014-04-09 13:18
 |  | Max: |  | 14 |  |  |  |  |  | $799.00
 |  | Avg: |  | 9.230769231 |  |  |  |  |  | $423.53
 | Round 1:
 | Already Own

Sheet: 4. Receivers
Receivers
Option | Brand | Line | Model | # of channels | Length (mm) | Width (mm) | Height (mm) | Operating Voltage | Mass (grams) | Price (US$) | Link
8 | Futaba | FASST 2.4GHz | R6014HS | 14 | 52.0 | 37.6 | 15.9 | 4.8-6 | 21.5 | $169.98 | www.gpdealera.com (http://www.gpdealera.com/cgi-bin/wgainf100p.pgm?I=FUTL7645)
1 | Futaba | FASST 2.4GHz | R6208SB | 8 | 47.3 | 24.9 | 14.3 | 3.7-7.4 | 13.8 | $129.99 | www.gpdealera.com (http://www.gpdealera.com/cgi-bin/wgainf100p.pgm?I=FUTL7668)
 | Futaba | FASST 2.4GHz | R617FS | 7 | 40.0 | 27.0 | 9.0 | 4.8-6 | 9.8 | $69.95 | www.gpdealera.com (http://www.gpdealera.com/cgi-bin/wgainf100p.pgm?I=FUTL7627)
 | JR | DMSS 2.4GHz | RG1131B | 11 | 47.5 | 32.0 | 14.0 | 4.5-8.5 | 18 | $129.99 | www.horizonhobby.com (http://www.horizonhobby.com/products/rg1131b-11-channel-dmss-full-range-receiver-with-ra-01t-telem-JRP03425)
 | JR | DMSS 2.4GHz | RG631B | 6 | 46.5 | 20.0 | 12.5 | 4.8-8.5 | 9 | $79.99 | www.horizonhobby.com (http://www.horizonhobby.com/products/rg631b-6ch-dmss-full-range-rx-with-ra-01-telem-JRP03426)
 | Spektrum | DSMX 2.4 GHz | AR8000 | 8 | 34.3 | 32.3 | 11.4 | 3.5-9.6 | 9.4 | $129.99 | www.spektrumrc.com (http://www.spektrumrc.com/Products/Default.aspx?ProdID=SPMAR8000)
 | Spektrum | DSMX 2.4 GHz | AR7610 | 7 | 34.3 | 29.2 | 11.4 | 3.5-9.6 | 8.9 | $89.99 | www.spektrumrc.com (http://www.spektrumrc.com/Products/Default.aspx?ProdID=SPMAR7610)
1 | Spektrum | DSMX 2.4 GHz | AR610 | 6 | 36.6 | 26.7 | 12.7 | ? | 9 | $49.99 | www.spektrumrc.com (http://www.spektrumrc.com/Products/Default.aspx?ProdID=SPMAR610)
 |  |  | MIN: | 6 | 34.3 | 20 | 9 |  | 8.9 | $49.99 | 2014-04-09 13:18
 |  |  | MAX: | 14 | 52 | 37.6 | 15.9 |  | 21.5 | $169.98
 |  |  | AVG: | 8.375 | 42.3125 | 28.7125 | 12.65 |  | 12.425 | $106.23
 | Round 1:
 | Recommended for my Tx
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

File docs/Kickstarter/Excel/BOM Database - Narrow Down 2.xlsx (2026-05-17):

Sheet: BOM Summary
ITEM NO. | CATEGORY | COMPONENT | BRAND | DROP DOWNS: | QTY. | MASS EACH (g) | TOTAL MASS (g) | PRICE EACH | TOTAL PRICE
1 | Hardware | Multirotor | Tarot | TL960A | 1 | 1050 | 1050 | $339 | $339
2 | Electronics | Flight Contoller | 3DRobotics | Pixhawk | 1 | 38 | 38 | $199.99 | $199.99
3 | Electronics | Transmitter | Futaba | T8FG Super | 1 | 0 | 0 | $479 | $479
4 | Electronics | Receiver | Futaba | R6208SB | 1 | 13.8 | 13.8 | $129.99 | $129.99
5 | Electronics | Camera | GoPro | Hero 3+ Black | 1 | 74 | 74 | $399.99 | $399.99
6 | Electronics | Gimbal | DJI | H3-3D | 1 | 168 | 168 | $399 | $399
7 | Electronics | Motor | Tiger | U3-700 | 6 | 97 | 582 | $109.9 | $659.4
8 | Electronics | ESC | T-Motor | T 30 | 6 | 25 | 150 | $28.99 | $173.94
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

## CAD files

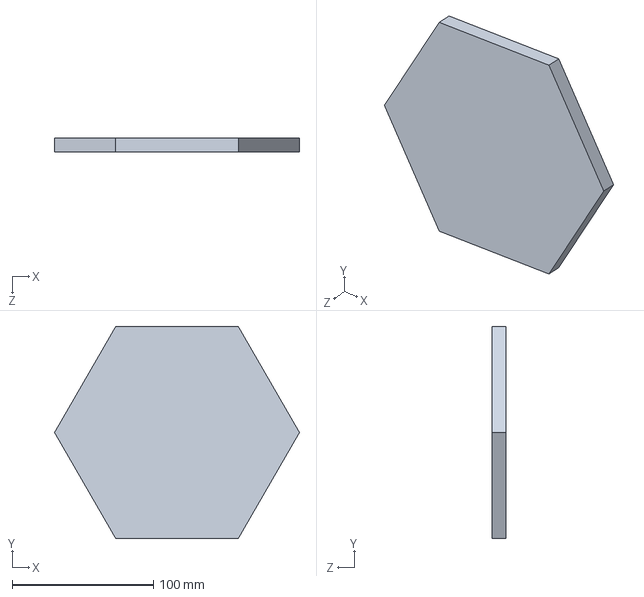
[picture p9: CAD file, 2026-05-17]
CAD/Kiwi MultiKopter/6. Hexacopters/HexaKiwi - Main Frame Cap - Ver. A.SLDPRT
173.2 x 150.0 x 10.0 mm

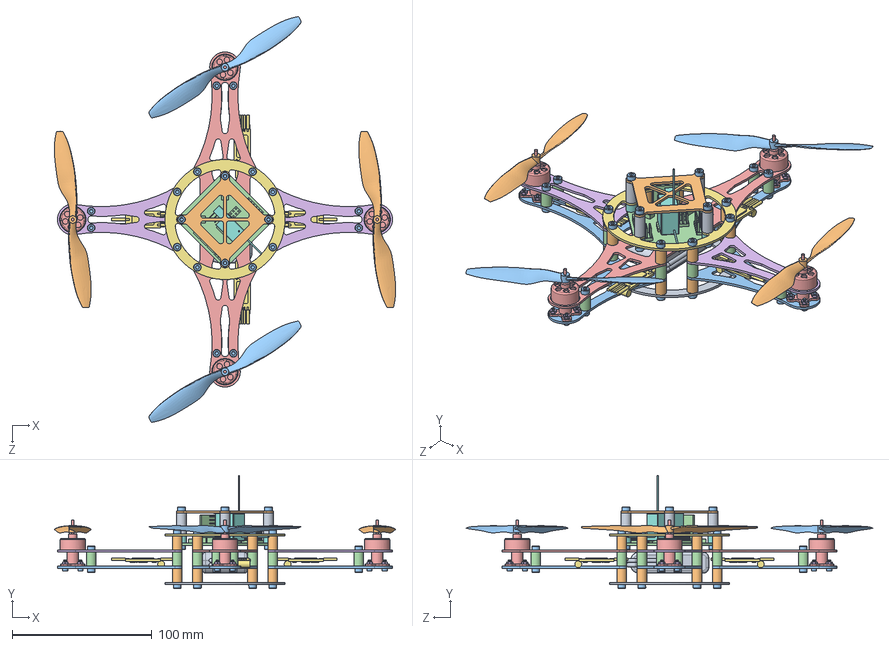
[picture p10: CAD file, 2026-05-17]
CAD/Original QRM 3D Solidworks Model/SolidWorks 2012/Quad Rotor Mini.SLDASM
244.4 x 81.0 x 290.7 mm
QRM004 - Bottom Frame Ring
QRM102 - Frame Spacer 10mm x 16
QRM001 - Bottom Arm x 4
QRM104 - Threaded Frame Spacer 10mm x 16
QRM003 - Battery Tray
QRM002 - Top Arm x 2
QRM005 - Top Frame Ring
QRM101 - Frame Spacer 5mm x 4
QRM103 - Frame Spacer 15mm x 4
QRM006 - Electronic Cover
socket head cap screw_din x 56
HobbyKing Multi-Rotor Control Board
18-11 2000kv Micro Brushless Outrunner x 4
hex nut style 1 gradeab_din x 16
TURNIGY Plush 6A Speed Controller x 4
Spektrum AR6110
Turnigy nano-tech 850mah 2S Lipo Pack
5x3L Propeller x 2
5x3R Propeller x 2

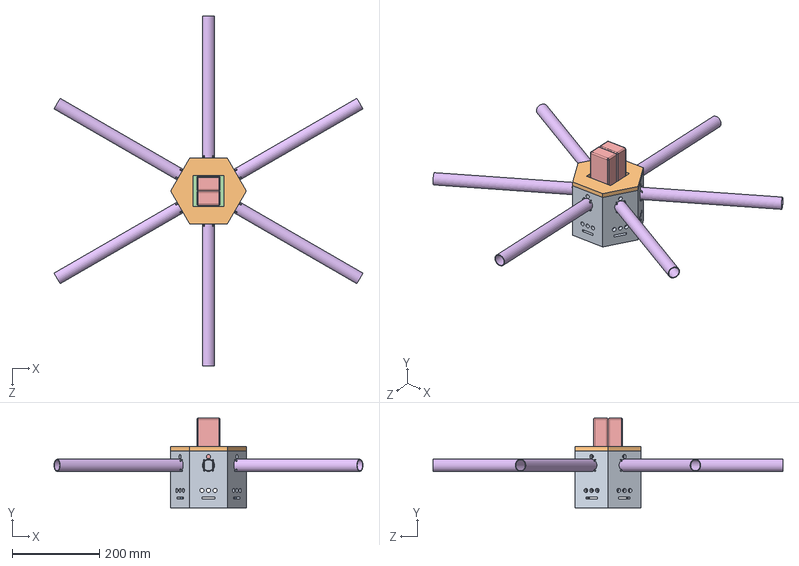
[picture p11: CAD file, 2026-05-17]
CAD/Kiwi MultiKopter/6. Hexacopters/HexaKiwi - Ver. A.SLDASM
706.8 x 205.5 x 800.0 mm
HexaKiwi - Main Frame - Ver. A x 6
HexaKiwi - Main Frame Cap - Ver. A
HexaKiwi - Electronics Board - Ver. A x 6
HexaKiwi - Bottom Electronics Board - Ver. A
HexaKiwi - 5800mAh 4S 35C Battery - Ver. A
HexaKiwi - Boom - Ver. A x 6

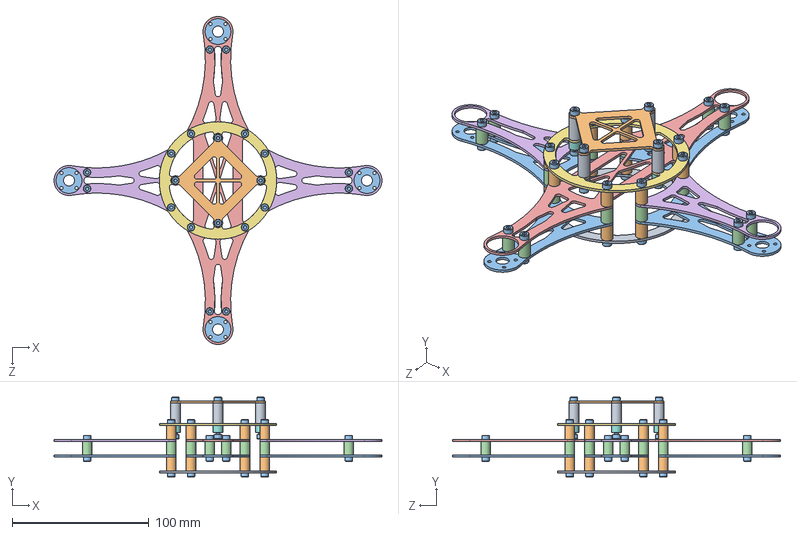
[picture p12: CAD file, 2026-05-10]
CAD/Quadcopter/SolidWorks 2012/QRM Frame.SLDASM
239.9 x 58.5 x 240.0 mm
QRM004 - Bottom Frame Ring
QRM102 - Frame Spacer 10mm x 16
QRM001 - Bottom Arm x 4
QRM104 - Threaded Frame Spacer 10mm x 16
QRM003 - Battery Tray
QRM002 - Top Arm x 2
QRM005 - Top Frame Ring
QRM101 - Frame Spacer 5mm x 4
QRM103 - Frame Spacer 15mm x 4
QRM006 - Electronic Cover
socket head cap screw_din x 40

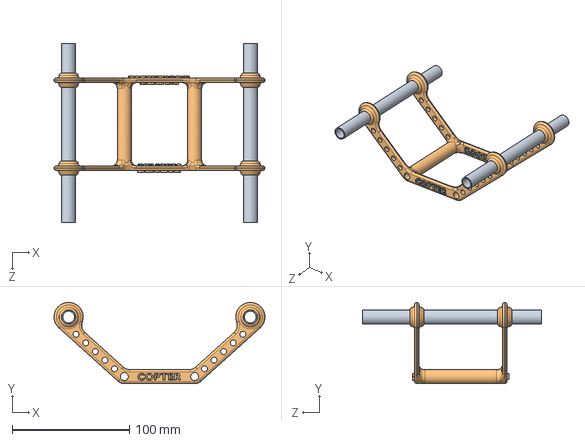
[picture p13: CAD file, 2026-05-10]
CAD/Hexacopter Gimbal Mount/Gimbal Assembly.SLDASM
180.0 x 69.3 x 152.4 mm
Wide Rails
Gimbal Mount V2

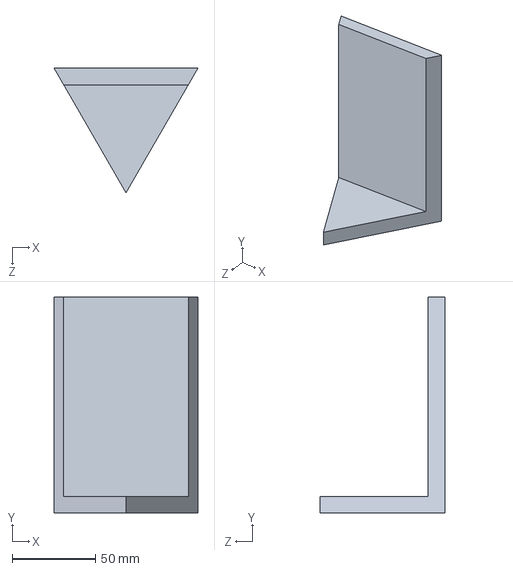
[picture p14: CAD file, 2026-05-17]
CAD/Kiwi MultiKopter/6. Hexacopters/HexaKiwi - Main Frame - Ver. A.SLDPRT
86.6 x 130.0 x 75.0 mm

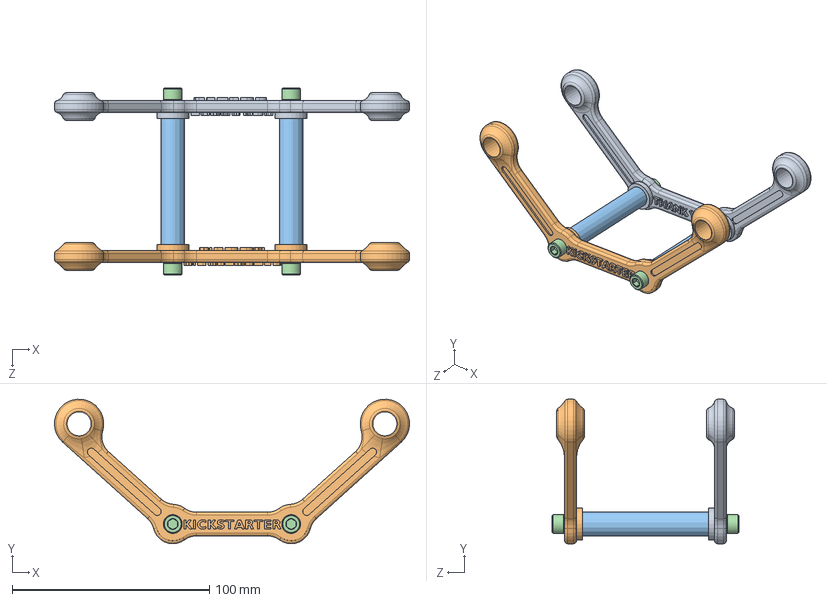
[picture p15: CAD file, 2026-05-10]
CAD/Hexacopter Gimbal Mount/Gimba Assemby V3.SLDASM
180.0 x 73.3 x 94.7 mm
Gimbal Mount V3 Back Piece
Gimbal Mount V3 Front Piece
Gimbal Mount V3 Rod x 2
Socket Cap Quarter 20 x 4

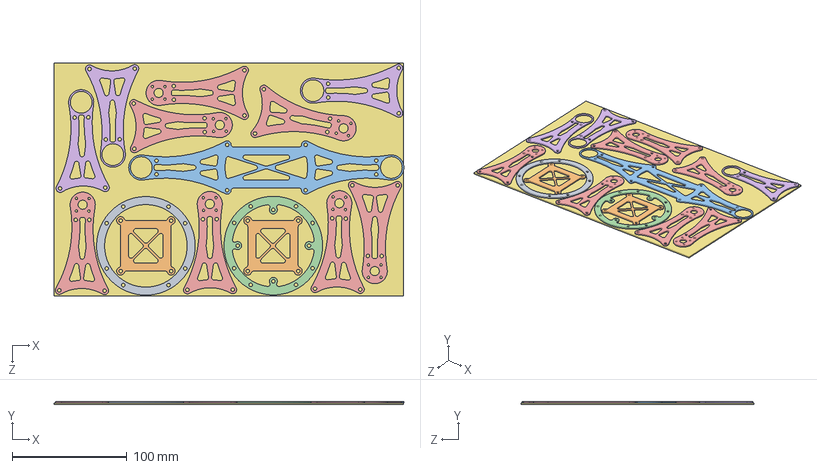
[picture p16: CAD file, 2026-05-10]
CAD/Quadcopter/SolidWorks 2012/CNC Layout.SLDASM
305.1 x 3.00 x 203.2 mm
QRM004 - Bottom Frame Ring
QRM006 - Electronic Cover x 2
QRM003 - Battery Tray
QRM005 - Top Frame Ring
QRM001 - Bottom Arm x 7
QRM002 - Top Arm x 3
Carbon Fiber Footprint

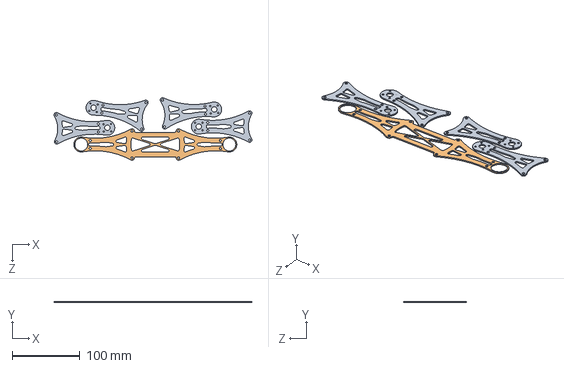
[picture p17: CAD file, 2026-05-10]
CAD/Quadcopter/SolidWorks 2012/Stencil Layout.SLDASM
291.4 x 1.50 x 92.2 mm
QRM001 - Bottom Arm x 4
QRM003 - Battery Tray

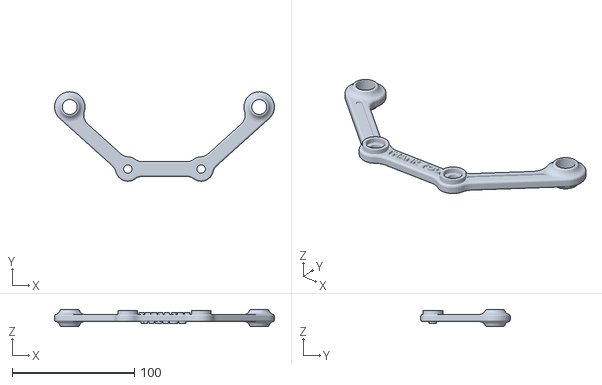
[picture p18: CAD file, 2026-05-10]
CAD/Hexacopter Gimbal Mount/Final Print/Back Piece V4.STL
180.0 x 73.3 x 14.0

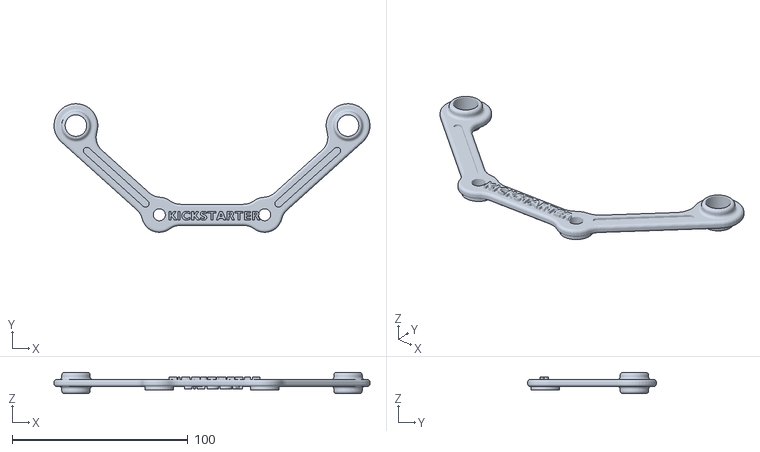
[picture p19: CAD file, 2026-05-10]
CAD/Hexacopter Gimbal Mount/New folder/Gimbal Mount V3 Front Piece.STL
180.0 x 73.3 x 12.0

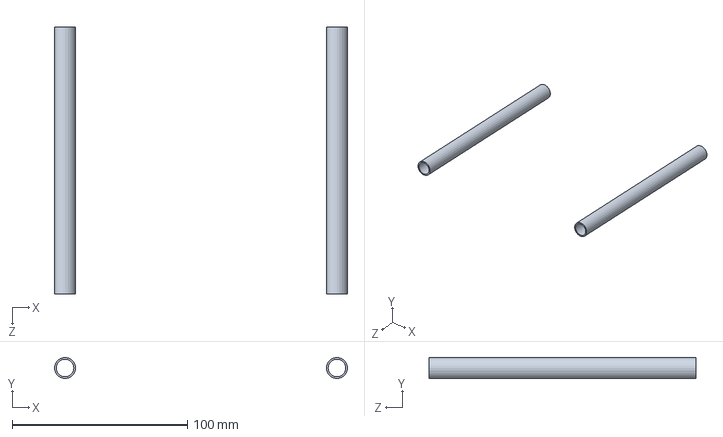
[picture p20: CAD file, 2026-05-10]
CAD/Hexacopter Gimbal Mount/Wide Rails.SLDPRT
167.0 x 12.0 x 152.4 mm

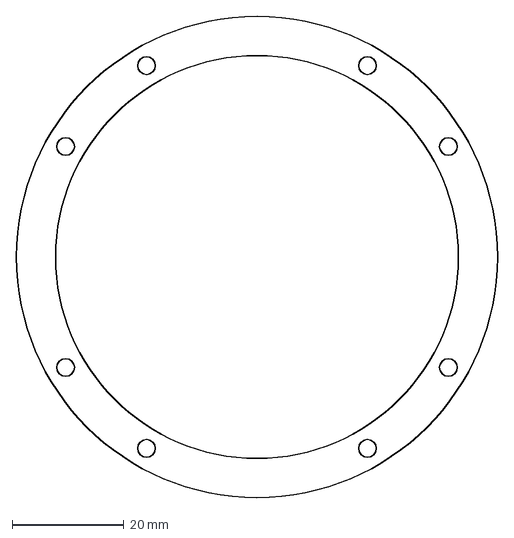
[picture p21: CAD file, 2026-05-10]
CAD/Original QRM 3D Solidworks Model/DXF/QRM004 - Bottom Frame Ring.DXF
86.0 x 86.0 mm

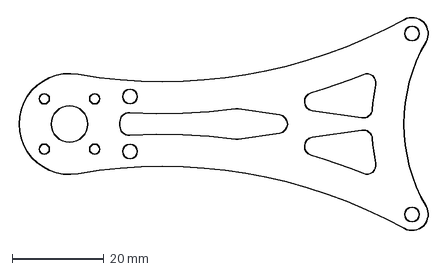
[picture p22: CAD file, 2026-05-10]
CAD/Quadcopter/DXF/QRM001 - Bottom Arm.DXF
90.2 x 47.1 mm

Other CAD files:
CAD/Quadcopter/SolidWorks 2012/Quad Rotor Mini.SLDASM
CAD/Hexacopter Gimbal Mount/Final Print/Front Piece V4.STL
CAD/Hexacopter Gimbal Mount/Gimbal Mount.SLDPRT
CAD/Hexacopter Gimbal Mount/Final Print/Rod V4.STL
CAD/Hexacopter Gimbal Mount/Gimba Mount V3 Rods.SLDPRT
CAD/Hexacopter Gimbal Mount/Gimbal Mount V2.SLDPRT
CAD/Hexacopter Gimbal Mount/Gimbal Mount V3 Back Piece.SLDPRT
CAD/Hexacopter Gimbal Mount/Gimbal Mount V3 Front Piece.SLDPRT
CAD/Hexacopter Gimbal Mount/Gimbal Mount V3 Rod.SLDPRT
CAD/Hexacopter Gimbal Mount/Gimbal Mount V3.SLDPRT
CAD/Hexacopter Gimbal Mount/New folder/12mm gimbal test print.SLDPRT
CAD/Hexacopter Gimbal Mount/New folder/12mm gimbal test print.STL
CAD/Hexacopter Gimbal Mount/New folder/Gimbal Mount V3 Back Piece.STL
CAD/Hexacopter Gimbal Mount/New folder/Gimbal Mount V3 Rod.STL
CAD/Hexacopter Gimbal Mount/New folder/Rod Test Print.SLDPRT
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

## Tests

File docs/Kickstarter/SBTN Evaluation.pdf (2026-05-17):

## Certificate of Completion

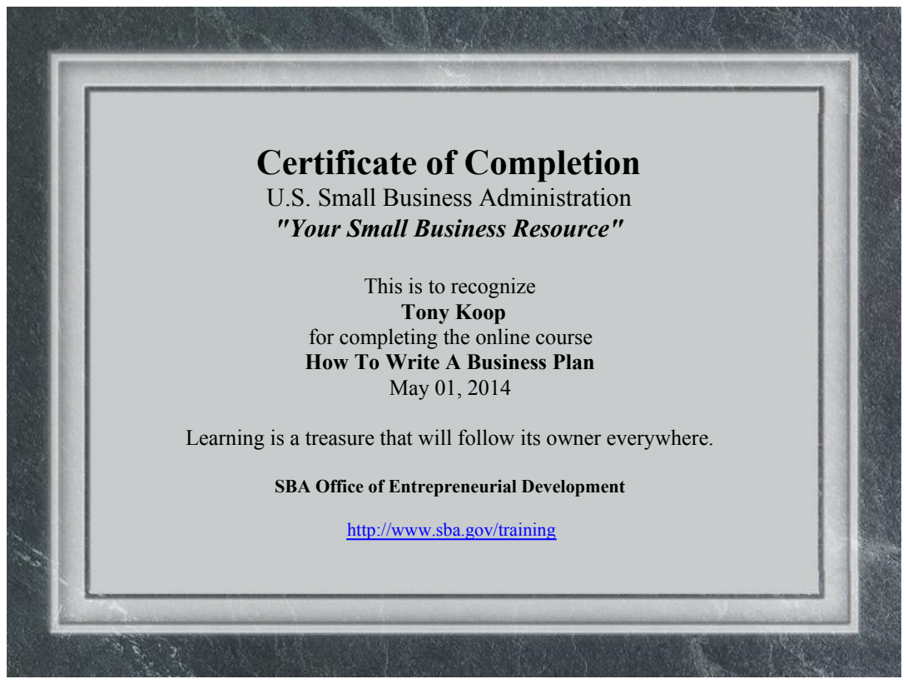
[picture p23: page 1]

U.S. Small Business Administration "Your Small Business Resource"

This is to recognize
Tony Koop
for completing the online course How To Write A Business Plan May 01, 2014

Learning is a treasure that will follow its owner everywhere.

SBA Office of Entrepreneurial Development

http://www.sba.gov/training

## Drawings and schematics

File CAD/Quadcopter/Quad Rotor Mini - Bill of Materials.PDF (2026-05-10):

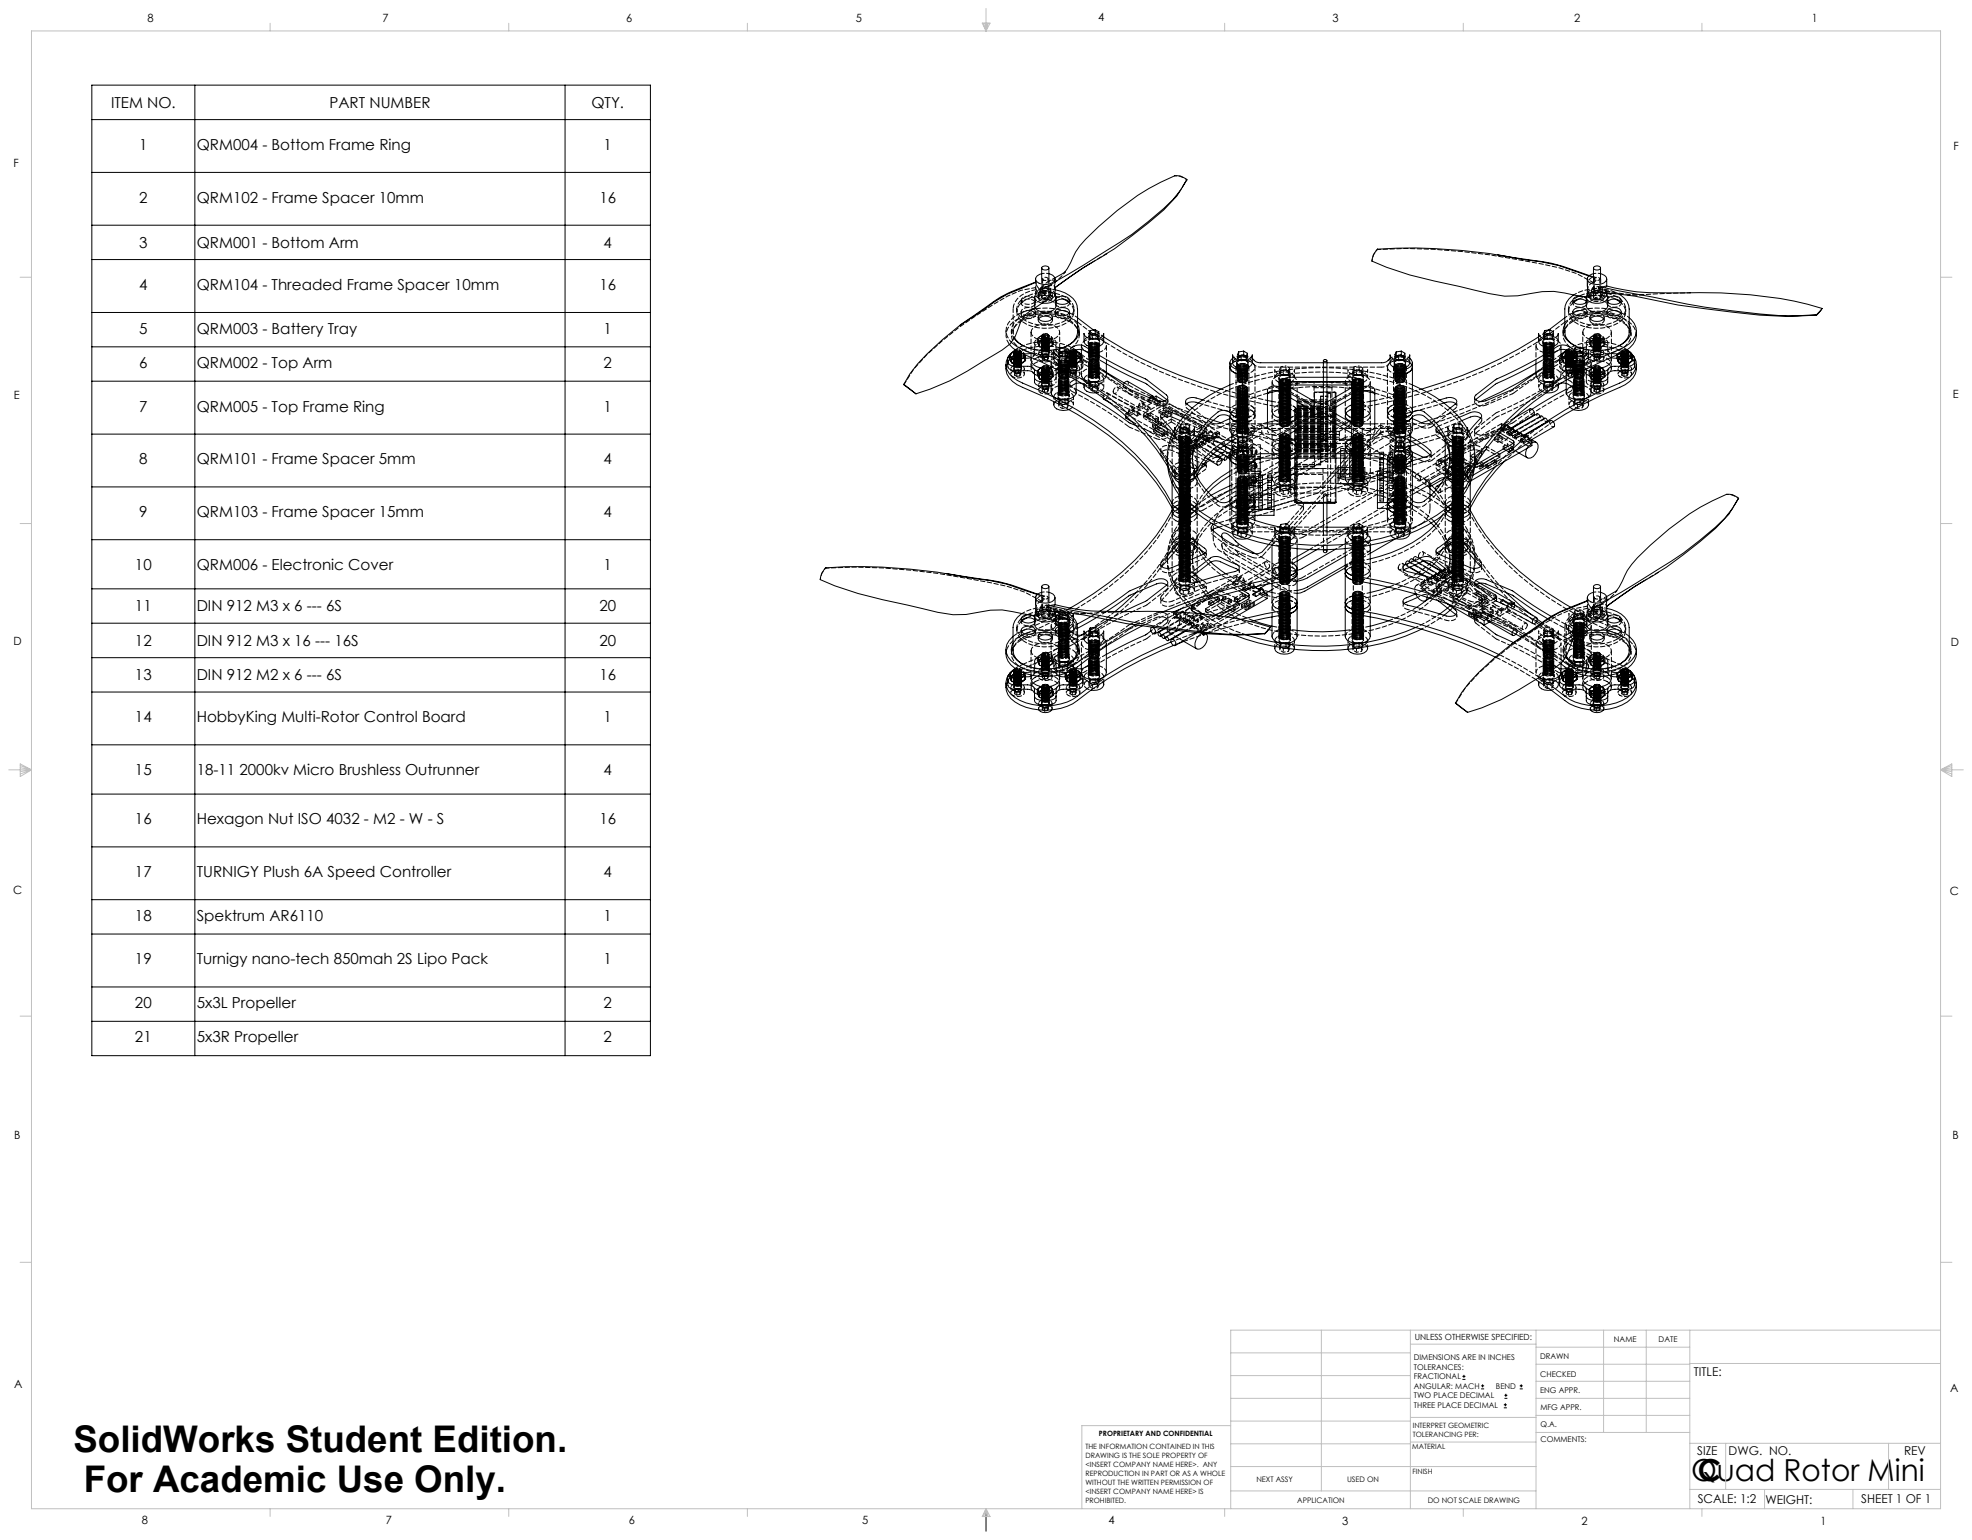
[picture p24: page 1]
Quad Rotor Mini; SHEET 1 OF 1; SCALE: 1:2 WEIGHT:; DWG. NO.; REV; MFG APPR.; ENG APPR.; INTERPRET GEOMETRIC TOLERANCING PER:; ANGULAR: MACH; BEND; NEXT ASSY; USED ON

ITEM NO. | PART NUMBER | QTY.

1 | QRM004 - Bottom Frame Ring | 1

2 | QRM102 - Frame Spacer 10mm | 16

3 | QRM001 - Bottom Arm | 4

4 | QRM104 - Threaded Frame Spacer 10mm | 16

5 | QRM003 - Battery Tray | 1
6 | QRM002 - Top Arm | 2

7 | QRM005 - Top Frame Ring | 1

8 | QRM101 - Frame Spacer 5mm | 4

9 | QRM103 - Frame Spacer 15mm | 4

10 | QRM006 - Electronic Cover | 1

11 | DIN 912 M3 x 6 --- 6S | 20
12 | DIN 912 M3 x 16 --- 16S | 20
13 | DIN 912 M2 x 6 --- 6S | 16

14 | HobbyKing Multi-Rotor Control Board | 1

15 | 18-11 2000kv Micro Brushless Outrunner | 4

16 | Hexagon Nut ISO 4032 - M2 - W - S | 16

17 | TURNIGY Plush 6A Speed Controller | 4

18 | Spektrum AR6110 | 1

19 | Turnigy nano-tech 850mah 2S Lipo Pack | 1

20 | 5x3L Propeller | 2
21 | 5x3R Propeller | 2

UNLESS OTHERWISE SPECIFIED:

DIMENSIONS ARE IN INCHES
TOLERANCES:
FRACTIONAL
TWO PLACE DECIMAL
THREE PLACE DECIMAL

SolidWorks Student Edition.
For Academic Use Only.

PROPRIETARY AND CONFIDENTIAL
THE INFORMATION CONTAINED IN THIS
DRAWING IS THE SOLE PROPERTY OF
<INSERT COMPANY NAME HERE>. ANY
REPRODUCTION IN PART OR AS A WHOLE
WITHOUT THE WRITTEN PERMISSION OF
<INSERT COMPANY NAME HERE> IS
PROHIBITED.

DO NOT SCALE DRAWING

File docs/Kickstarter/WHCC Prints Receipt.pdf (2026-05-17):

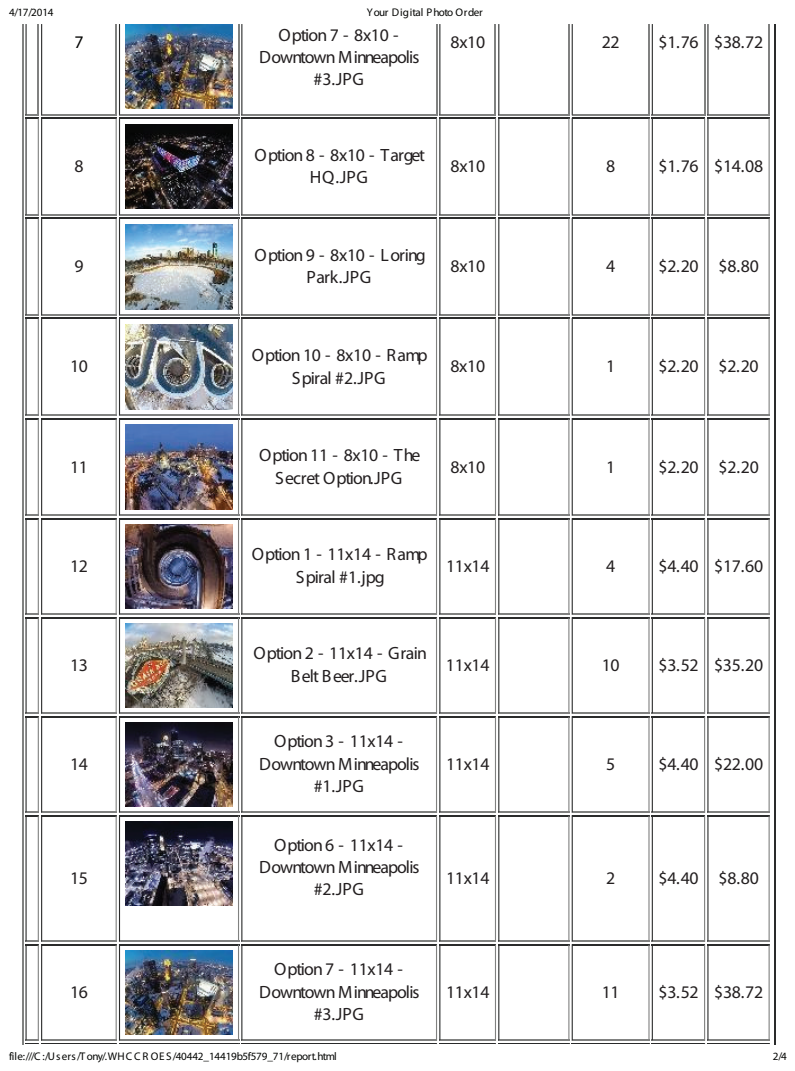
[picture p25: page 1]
Your Digital Photo Order; file:///C :/Users/Tony/.WHC C R OE S /40442_14419b5f579_71/report.html; Option7 - 8x10 -; DowntownMinneapolis #3.JPG; Option8 - 8x10 - Target; HQ.JPG; Option9 - 8x10 - Loring; Park.JPG; Option10 - 8x10 - Ramp; Spiral #2.JPG; Option11 - 8x10 - The; SecretOption.JPG; Option1 - 11x14 - Ramp; Spiral #1.jpg; Option2 - 11x14 - Grain; Belt Beer.JPG; Option3 - 11x14 - DowntownMinneapolis #1.JPG; Option6 - 11x14 - DowntownMinneapolis; #2.JPG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

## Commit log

2026-04-26 Build out README: Phantom -> fly-away -> Kickstarter -> unfinished hexacopter; CC-BY 4.0
    Honest framing of the unfinished build. Three-act story (Phantom
    era + skyline aerials, fly-away during Bracketron demo,
    Kickstarter-funded hexacopter rebuild with 3D-printed DSLR gimbal),
    the explicit "I stopped because I lacked firmware confidence"
    decision, and a "documentation discipline is independent of
    execution discipline" framing for why the unfinished build still
    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
2026-05-17 cad photos
    [12mm gimbal test print.SLDPRT, 12mm gimbal test print.STL, 18-11 2000kv Micro Brushless Outrunner.SLDPRT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]
2026-06-17 docs(readme): trim repeated backer-obligation theme to one disclosure
    Reduce the "outstanding Kickstarter backer obligation" theme from ~4
    narrative mentions to a single factual line; let engineering substance
    and the grounding/validation judgment carry the page.
    - Remove the backer-owed clause from the opening blockquote
    - Condense the single "Reward still outstanding:" line (the one place
    the obligation lives)
    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
2026-06-17 docs(readme): add hero, aerial, and technical photos
    - Hero: aerial skyline canvas wraps (Slide_photography.jpg), replacing the
    "hero photo forthcoming" placeholder
    - Phantom-era section: signed aerial canvas wrap (aerialphoto5.jpg)
    - Crowdfunded rebuild section: motor arms + ESCs measured against a caliper
    and steel rule (ADK_4465.JPG)
    All three image files already exist in images/ on main; this only adds the
    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
2026-06-17 docs(readme): reconcile "forthcoming" status with photos now in repo
    The page now shows three photos, so the status claims contradicted it. Fix:
    - Update the "Engineering content" intro: README + license + an initial set
    of photos are in (engineering docs still being recovered), no longer
    "README + LICENSE only"
    - Flip the Phantom-era aerial and Build photo table rows to ✓ done
    - Move images/ out from under the "(forthcoming)" label in the repo tree,
    since it is populated
    BOM/CAD/notebook/firmware rows remain forthcoming.
